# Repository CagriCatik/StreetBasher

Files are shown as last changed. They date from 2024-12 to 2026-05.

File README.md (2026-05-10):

<h1 align="center">StreetBasher: 3D-Printed RC Car Project</h1>

<p align="center">
  
  
</p>

**StreetBasher** is an open-source, 3D-printed RC car designed for enthusiasts who love customization, engineering, and high-speed fun. This project provides everything you need to **assemble, modify, and fine-tune your own RC car**, including **detailed assembly guides, 3D-printable parts, and tuning instructions**.

**Build it. Customize it. Race it!**

---

## **Project Highlights**
- **Fully 3D-Printed Design:** Print your own chassis, suspension, and other essential components.
- **Customizable:** Modify the design to fit your preferences, from gearing ratios to wheel types.
- **Electronics & Hardware Integration:** Supports standard RC electronics, motors, and batteries.
- **Step-by-Step Documentation:** Easy-to-follow instructions for assembly and tuning.

---

## **Project Structure**
```
StreetBasher/
│── .github/workflows/       # GitHub Actions for automation & deployment
│── instructions/            # Documentation & assembly guides
│   ├── docs/                # MkDocs-based documentation
│   ├── sldprts/             # SolidWorks design files
│   ├── stls/                # STL files for 3D printing
│   ├── mkdocs.yml           # Configuration for MkDocs documentation
│── original/                # Raw design files or legacy versions
│── .gitignore               # Ignored files
│── README.md                # Project overview (this file)
│── requirements.txt         # Dependencies for documentation setup
```

---

## **Getting Started**
### **1. Print the Parts**
Download the **STL files** from the `instructions/stls/` folder or from the official **Printables page**:  
**[StreetBasher on Printables](https://www.printables.com/model/700706-street-basher-3d-printed-rc-car-17)**

### **2. Gather the Components**
You will need the following:
- **3D-printed parts** (chassis, arms, suspension, etc.)
- **RC Electronics:** Brushless motor, ESC, receiver, and transmitter
- **Battery pack** (LiPo recommended)
- **Servo motor** for steering
- **Screws & Fasteners** (size details in the docs)

### **3. Assemble & Tune**
Follow the **step-by-step assembly guide** in `instructions/docs/` to build your RC car.  
Once built, fine-tune it using the tuning instructions for **better handling and speed**.

---

Complete guides, 3D model previews, and technical tutorials are available in the official documentation portal.

[**View Documentation Portal**](https://cagricatik.github.io/StreetBasher/)

---

## **Documentation Highlights**
- **Interaktive 3D Previews**: View every part directly in your browser.
- **Detailed BOM**: Full parts list with direct purchase links and cost analysis.
- **Assembly Guides**: Step-by-step instructions for a successful build.

---

## **Getting Started**
```sh
# Install dependencies
pip install -r requirements.txt

# Run MkDocs
mkdocs serve
```
Then open **http://127.0.0.1:8000** in your browser.

---

**Source:** [StreetBasher on Printables](https://www.printables.com/model/700706-street-basher-3d-printed-rc-car-17)

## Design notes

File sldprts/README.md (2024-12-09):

# SolidWorks Parts

---

## Chassis
| Part Name | Status | Material | Supports |
|---|---|---|---|
| Center_Front_bumper.sldprt | ✅ | Tough / Standard  | Yes |
| Front_body_brace_1.sldprt | ❌ | Tough / Standard  | No |
| Front_body_brace_2.sldprt | ❌ | Tough / Standard  | No |
| Front_body_brace_insert.sldprt| ❌ | Standard | No |
| Front_spliter.sldprt | ❌ | Tough / Flexible  | No |
| Rear_difuser_body.sldprt | ❌ | Standard | Yes |
| Rear_wing_brace_L.sldprt | ❌ | Tough / Standard  | No |
| Rear_wing_brace_R.sldprt | ❌ | Tough / Standard  | No |
| Center_body.sldprt | ❌ | Standard | Yes |
| Front_body.sldprt | ❌ | Standard | Yes |
| Front_brace.sldprt | ❌ | Standard | No |
| Rear_body.sldprt | ❌ | Standard | Yes |
| Rear_brace.sldprt | ❌ | Standard | No |

---

## Body Roll Cage

| Part Name | Status | Material | Supports |
|---|---|---|---|
| Back_Bottom_L.stl | ❌ | Tough / Flexible | Yes |
| Back_Bottom_R.stl | ❌ | Tough / Flexible | Yes |
| Back_Cage.stl | ❌ | Tough / Flexible | Yes |
| Back_Roof.stl | ❌ | Tough / Flexible | No |
| Back_Top_L.stl | ❌ | Tough / Flexible | No |
| Back_Top_R.stl | ❌ | Tough / Flexible | No |
| Front_bumper_bottom.stl | ❌ | Flexible | No |
| Front_bumper_holder_L.stl | ❌ | Flexible | No |
| Front_bumper_holder_R.stl | ❌ | Flexible | No |
| Front_bumper_L.stl | ❌ | Flexible | No |
| Front_bumper_R.stl | ❌ | Flexible | No |
| Front_bumper_top.stl | ❌ | Flexible | No |
| Hood_panel.stl | ❌ | Tough / Flexible | No |
| Mud_Guard.stl | ❌ | Tough / Flexible | Yes |
| Roof.stl | ❌ | Tough / Flexible | No |
| Roof_Panel.stl | ❌ | Tough / Flexible | No |
| Side_L.stl | ❌ | Tough / Flexible | Yes |
| Side_R.stl | ❌ | Tough / Flexible | Yes |

---
## Center Drive
---
## Electronics
---
## Differential
---
## Sway Bar
---
## Front Suspension
---
## Rear Suspension
---
## Steering
---
## Wing

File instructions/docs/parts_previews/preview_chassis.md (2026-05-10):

# Chassis 3D Previews

Explore all Chassis components in 3D. Drag to rotate, scroll to zoom.

---

## Front-Bumper Components

### Center Front Bumper

### Front Body Brace 1

### Front Body Brace 2

### Front Body Brace Insert

### Front Spliter

## Rear-Diffuser Components

### Rear Diffuser Body

### Rear Wing Brace L

### Rear Wing Brace R

## General Chassis Components

### Center Body

### Front Body

### Front Brace

### Rear Body

### Rear Brace

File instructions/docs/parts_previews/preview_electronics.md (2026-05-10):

# Electronics 3D Previews

Explore all Electronics components in 3D. Drag to rotate, scroll to zoom.

---

### Battery Tray L

### Battery Tray R

### Ele Box Body Esc

### Ele Box Body Wp8Bl150

### Ele Cover

### Fan Shroud

### On Off Switch Holder Wp8Bl150

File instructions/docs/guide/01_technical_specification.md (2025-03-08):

# **Technical Specification**

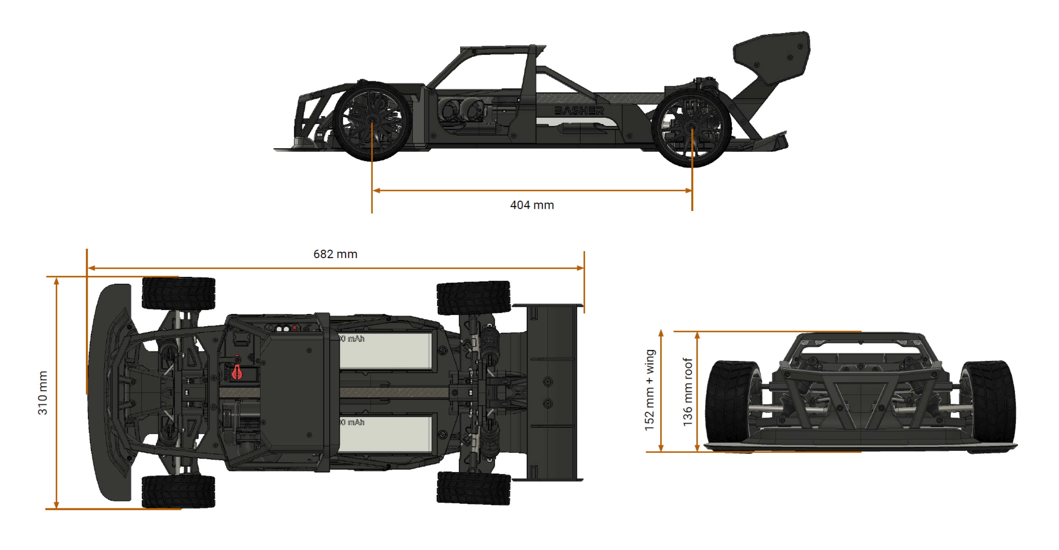
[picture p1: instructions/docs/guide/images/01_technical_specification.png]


## **1. General Information**
- **Model Name**: StreetBASHER  
- **Type**: High-performance RC Car Chassis (3D Printable)  
- **Application**: Hobbyist & Competitive RC Car Racing  
- **Scale**: Approx. 1:8  

## **2. Dimensions**
- **Overall Length**: 682 mm  
- **Wheelbase**: 404 mm  
- **Overall Width**: 310 mm  
- **Overall Height**:  
  - 136 mm (roof height)  
  - 152 mm (including rear wing)  

## **3. Chassis & Frame**
- **Material**:  
  - **Recommended Filaments**: PLA+ (for prototyping), PETG, ABS, or Nylon (for durability)  
  - **Reinforced Sections**: Carbon Fiber Nylon (for stress-prone areas)  
- **Construction**: Modular frame with a reinforced roll cage  
- **Mounting Points**: Designed for M3 & M4 bolts for securing electronic components  
- **Battery Tray Size**: Fits standard 2S-4S LiPo battery packs  
- **Cooling & Ventilation**: Open-frame design for airflow  

## **4. Suspension System**
- **Independent Suspension**: Double wishbone front & rear  
- **Shock Mounting**: Adjustable shock absorber mounting points  
- **Shock Absorbers**: 3D-printable dampers (supports oil-filled aluminum shocks for better performance)  

## **5. Drivetrain & Wheels**
- **Drive Type**: 4WD (Modular for RWD conversion)  
- **Differentials**: Space for customizable gear differentials  
- **Wheel Hub Mount**: 12 mm hex hubs (compatible with standard RC wheels)  
- **Tire Compatibility**: Off-road & on-road rubber tires (3D-printable wheels with TPU tires)  

## **6. Electronics & Powertrain**
- **Motor Mounting**: Supports 540/550 brushless or brushed motors  
- **ESC Mounting**: Space for 60A-120A ESC with ventilation slots  
- **Servo Mount**: Standard 25T servo horn compatibility  
- **Receiver & Electronics Bay**: Dedicated space for receiver & wiring management  
- **Battery Type**: LiPo 2S-4S compatible with secure mounting  

## **7. Aerodynamics & Body Design**
- **Front Splitter**: Designed for downforce and handling stability  
- **Rear Wing**: Adjustable wing for aerodynamic tuning  
- **Body Panels**: Modular, detachable panels for easy replacement  
- **3D Printability Considerations**:  
  - Split into sections for easy printing and assembly  
  - Support-free design where possible  
  - Optimized wall thickness for weight reduction  

## **8. Assembly & Hardware Requirements**
- **Fasteners**: M3 & M4 screws, lock nuts, washers  
- **Bearings**: 8x16x5 mm standard RC bearings  
- **Axles & Drive Shafts**: Compatible with 3D-printed or metal options  

## **9. Printing Guidelines**
- **Recommended Print Settings**:  
  - **Layer Height**: 0.2 mm for fine detail, 0.3 mm for strength  
  - **Infill**: 30%-50% (higher in stress areas)  
  - **Wall Thickness**: 2-3 mm for structural parts  
  - **Supports**: Minimal (optimized for overhangs and bridges)  
- **Material Notes**:  
  - PLA+ for prototyping  
  - PETG or ABS for functional parts  
  - TPU for flexible parts (bumpers, tires)  
  - Carbon Fiber Nylon for chassis reinforcement

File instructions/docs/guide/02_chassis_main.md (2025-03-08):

# Chassis Assembly 

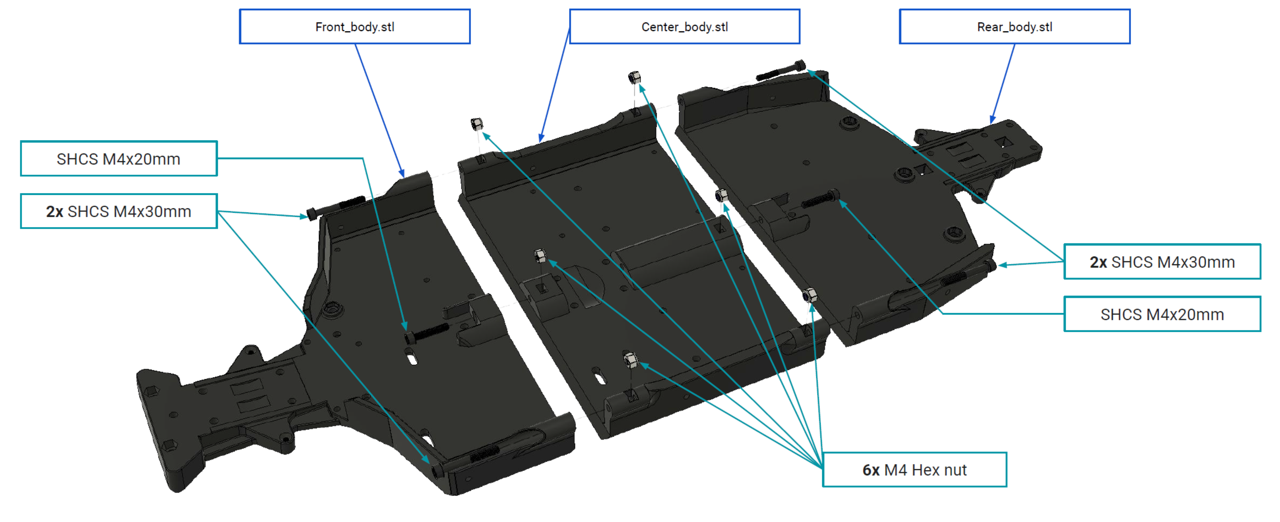
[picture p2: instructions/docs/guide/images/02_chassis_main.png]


## Chassis Components

The chassis is composed of three main parts:

- **Front_body.stl** - The front section of the chassis, which houses essential components such as the steering mechanism.
- **Center_body.stl** - The middle section of the chassis, which connects the front and rear sections and serves as the structural base for the electronic components.
- **Rear_body.stl** - The rear section of the chassis, which provides mounting points for the drivetrain and suspension components.

## Fasteners and Assembly Hardware
The assembly of the chassis requires the following fasteners:

- **SHCS (Socket Head Cap Screw) M4x20mm** - Used to join the front and center chassis sections.
- **2x SHCS M4x30mm** - Used to reinforce the connection between the front and center chassis.
- **2x SHCS M4x30mm** - Used to connect the center and rear chassis sections.
- **SHCS M4x20mm** - Additional reinforcement screw for securing the rear chassis.
- **6x M4 Hex Nuts** - Used to secure the M4 screws and prevent loosening during operation.

## Assembly Instructions

### Step 1: Preparing the Parts

1. Print the three chassis parts: **Front_body.stl, Center_body.stl, and Rear_body.stl** using a high-strength filament such as PETG or ABS for durability.
2. Ensure all printed parts are clean and free of excess filament or debris.

### Step 2: Connecting the Front and Center Sections

1. Align the **Front_body.stl** and **Center_body.stl** so that the mounting holes match.
2. Insert **SHCS M4x20mm** into the designated holes and loosely secure them.
3. Insert **2x SHCS M4x30mm** for added stability.
4. Attach **M4 Hex Nuts** to the screws and tighten them securely using an Allen key and a wrench.

### Step 3: Connecting the Center and Rear Sections

1. Align the **Center_body.stl** with **Rear_body.stl**, ensuring a proper fit.
2. Insert **2x SHCS M4x30mm** through the mounting holes.
3. Secure the screws using **M4 Hex Nuts** and tighten appropriately.
4. Insert the additional **SHCS M4x20mm** as a reinforcement screw and secure it with an **M4 Hex Nut**.

### Step 4: Final Tightening and Inspection

1. Verify all screws are tightened securely but not overtightened to avoid damaging the plastic.
2. Ensure that the chassis sections are properly aligned and free from gaps.
3. Check the structural integrity by applying light pressure to confirm a rigid connection.

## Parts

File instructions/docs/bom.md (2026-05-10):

# Bill of Materials

---

> [!NOTE]
> Looking for a price estimate? Check the detailed [Cost Analysis](cost_analysis.md) for a full breakdown of the build expenses.

## Drivetrain
| Part Name | Qty | Link  |
|---|-----|---|
| Front and rear Differential 43t + 10t pinion | 1x  | [link](https://s.click.aliexpress.com/e/_DezHD4Z) |
| Center differential 46t | 1x  | [link](https://s.click.aliexpress.com/e/_DBMWCD7) |
| CVD driveshaft Front | 2x  | [link](https://s.click.aliexpress.com/e/_DBLZZkv) |
| CVD driveshaft Back | 2x  | [link](https://s.click.aliexpress.com/e/_DCe5sf3) |
| Pinion gear 19T - 27T | 1x  | [link](https://s.click.aliexpress.com/e/_DE87qn7) |
| Drive shaft cup | 2x  | [link](https://s.click.aliexpress.com/e/_DnK3Nz7) |
| Driveshaft front to center (103.5mm) | 1x  | [link](https://s.click.aliexpress.com/e/_DmfG4It) |
| Driveshaft center to rear (170mm) | 1x  | [link](https://s.click.aliexpress.com/e/_DEjV5ez) |
| Wheel Hex | 4x  | [link](https://s.click.aliexpress.com/e/_DcxLlkt) |
| GRP 1:8 GT (S5 Medium) / Tyre 17mm Wheel Hex | 4x  | [link](https://s.click.aliexpress.com/e/_DkhpzbJ) |

---

## Electronics
| Part Name | Qty | Link  |
|---|-----|---|
| Servo + arm (DS3235 SSG-180) | 1x  | [link](https://s.click.aliexpress.com/e/_DDBty1r) |
| ESC 150A 6S / WP-8BL150 | 1x  | [link](https://s.click.aliexpress.com/e/_DdwzgTF) |
| Motor 4092 1420KV | 1x  | [link](https://s.click.aliexpress.com/e/_DEm0t2l) |
| Motor heatsink | 1x  | [link](https://s.click.aliexpress.com/e/_DCOEgbT) |
| 3s 5000mah (max dimensions 155x53mm) | 2x  | [link](https://chinahobbyline.com/products/cnhl-gplus-series-5000mah-11-1v-3s-70c-lipo-battery-with-xt90-plug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) |
| FlySky FS-GT5 +bs6 | 1x  | [link](https://s.click.aliexpress.com/e/_DkkQyyV) |

---

## Bearings
| Part Name | Qty | Link  |
|---|-----|---|
| 15x21x4mm (wheel inner) | 4x  | [link](https://s.click.aliexpress.com/e/_Dm0D3dj) |
| 8x16x5mm (wheel outer, diff) | 10x | |
| 5x11x4mm (diff pinion outer) | 2x  | |
| 8x19x6mm (diff pinion inner) | 2x  | |
| 6x10x3 (steering) | 4x  | |
| 3x6x2.5mm flange bearing (steering) | 4x  | [link](https://s.click.aliexpress.com/e/_DEKfLYD) |

---

## Screws
| Part Name | Qty  | Link  |
|---|---|---|
| M3 hex nut (self-locking) | 47x  | [link](https://s.click.aliexpress.com/e/_Dl5C057) |
| M4 hex nut (self-locking) | 50x  | |
| M3x7mm washer | 8x | [link](https://s.click.aliexpress.com/e/_Dl5C057) |
| M6x10mm Grub Screw | 4x | [link](https://s.click.aliexpress.com/e/_DdRgkKV) |
| M3x5mm Grub Screw | 8x | |
| SHCS M3x8mm | 5x | [link](https://s.click.aliexpress.com/e/_DkRgcZT) |
| SHCS M3x10mm | 13x  | |
| SHCS M3x14mm | 28x  | |
| SHCS M3x16mm | 7x | |
| SHCS M3x18mm | 10x  | |
| SHCS M3x20mm | 20x  | |
| SHCS M3x25mm | 17x  | |
| SHCS M3x30mm | 16x  | |
| FHCS M3x6mm | 4x | [link](https://s.click.aliexpress.com/e/_Dd5kyh3) |
| FHCS M3x10mm | 4x | |
| FHCS M3x12mm | 6x | |
| FHCS M3x14mm | 12x  | |
| FHCS M3x16mm | 8x | |
| SHCS M4x12mm | 13x  | [link](https://s.click.aliexpress.com/e/_DkRgcZT) |
| SHSC M4x16mm | 8x | |
| SHCS M4x20mm | 10x  | |
| SHCS M4x30mm | 8x | |
| SHCS M4x40mm | 2x | |
| SHCS M4x45mm | 4x | |
| SHCS M4x55mm | 2x | |
| SHCS M4x60mm | 4x | |
| SHCS M4x70mm | 4x | |
| FHCS M4x16mm | 11x  | [link](https://s.click.aliexpress.com/e/_Dd5kyh3) |
| FHCS M4x20mm | 4x | |

---

## Other
| Part Name | Qty | Link  |
|---|-----|---|
| Carbon center brace 15x15x13 (365mm) | 1x  | [link](https://s.click.aliexpress.com/e/_DdjCkoN) |
| Front arms pivot ball | 4x  | [link](https://s.click.aliexpress.com/e/_DB9CWiD) |
| Ball head 6.8x8.2x3 | 8x  | [link](https://s.click.aliexpress.com/e/_DCgGGoN) |
| Ball head 5.8x6x3 | 6x  | [link](https://s.click.aliexpress.com/e/_DCRDovT) |
| Front hub nut | 4x  | [link](https://s.click.aliexpress.com/e/_DmmpUX3) |
| Front and Rear Shocks | 1x  | [link](https://s.click.aliexpress.com/e/_DkQfMkZ) |
| Servo saver spring - 20mm length / 2mm wire / 16mm outer | 1x  | [link](https://s.click.aliexpress.com/e/_DFZ1YtB) |
| Arm link rear M5x50mm | 2x  | [link](https://s.click.aliexpress.com/e/_DBpFie1) |
| Arm link front M4x40mm | 2x  | [link](https://s.click.aliexpress.com/e/_DBpFie1) |
| Swaybar front | 1x  | ARA330257 |
| Swaybar rear | 1x  | ARAC9080 |
| Wheel shims M8x10x0.1 | 4-8x| [link](https://s.click.aliexpress.com/e/_DnN8B3B) |

---

## Accessories
| Part Name | Qty | Link  |
|---|-----|---|
| White lithium grease (external diff) | | |
| Oil 2000cSt (shocks) | | [link](https://s.click.aliexpress.com/e/_Dm6LZ6t) |
| Oil 100k cSt (center diff) | | |
| Oil 30k cSt (front/rear diff) | | |
| Loctite 243 | | |
| Battery strap 15-20mm x 240-280mm | 4x  | [link](https://s.click.aliexpress.com/e/_DEA4Nfr) |
| Foam padding 20mm 5mm thick | 1m  | [link](https://s.click.aliexpress.com/e/_DDHuyXL) |
| **Optional** Lipo Battery Voltage Tester | 1x  | [link](https://s.click.aliexpress.com/e/_DCnddTr) |

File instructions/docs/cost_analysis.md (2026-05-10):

# Project Cost Analysis

Estimated total cost for building the StreetBasher RC car based on current market prices (AliExpress, CNHL, etc.).

---

## Component Cost Breakdown

| Category | Item | Individual Price | Quantity | Subtotal |
| :--- | :--- | :--- | :--- | :--- |
| **Drivetrain** | Differential Set (Front/Rear) | 75.39 € | 1 Set | 75.39 € |
| | Center Differential | 56.84 € | 1 | 56.84 € |
| | Tires (GRP 1:8 GT Set) | 84.34 € | 1 Set | 84.34 € |
| **Electronics** | Servo (9imod 35kg High Torque) | 22.19 € | 1 | 22.19 € |
| | ESC 150A (Waterproof) | 143.98 € | 1 | 143.98 € |
| | Motor 4092 (Brushless) | 76.39 € | 1 | 76.39 € |
| | Battery 3S 5000mAh (CNHL) | 33.53 € | 2 | 67.06 € |
| | Transmitter (Flysky FS-GT5) | 72.53 € | 1 | 72.53 € |
| **Suspension** | Big Bore Shock Set | 45.78 € | 1 Set | 45.78 € |
| **Total Build Cost** | | | | **~644.50 €** |

---

## Savings & Optimization

> [!TIP]
> **Potential Savings: ~200 €+**
> 
> By utilizing "New User" discounts on AliExpress, current "Choice" deals, and combining shipping, the total cost can be reduced to approximately **439.22 €**.

### Tips for Procurement
*   **AliExpress Coins**: Use the mobile app to collect coins for additional 2-5% off.
*   **Choice Shipping**: Look for items marked as "Choice" for free 10-day shipping and combined delivery.
*   **Battery Safety**: Always order batteries from local warehouses (EU/US) to avoid long shipping times and customs issues.

---

*Note: Prices are subject to change and may vary based on region and shipping costs.*

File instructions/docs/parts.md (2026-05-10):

# Printed Part Lists

**Materials Key**

- **Tough**: PC-Max / PC-CF
- **Flexible**: TPU 98A
- **Standard**: [PLA Metall](https://eu.store.bambulab.com/de/products/pla-metall?variant=46797850902876)

---

## Chassis

### Front Parts

| Part Name | Status | Material | Supports | Link |
|---|---|---|---|---|
| Center_Front_bumper.stl | ✅ | Standard | Yes | [🔗](https://github.com/CagriCatik/StreetBasher/blob/main/stls/Chassis/Front-Bumper/Center_Front_bumper.stl) |
| Front_body_brace_1.stl | ✅ | Standard | No | [🔗](https://github.com/CagriCatik/StreetBasher/blob/main/stls/Chassis/Front-Bumper/Front_body_brace_1.stl) |
| Front_body_brace_2.stl | ✅ | Standard | No | [🔗](https://github.com/CagriCatik/StreetBasher/blob/main/stls/Chassis/Front-Bumper/Front_body_brace_2.stl) |
| Front_body_brace_insert.stl  | ✅ | Standard | No | [🔗](https://github.com/CagriCatik/StreetBasher/blob/main/stls/Chassis/Front-Bumper/Front_body_brace_insert.stl) |
| Front_spliter.stl | ✅ | Tough / Flexible | No | [🔗](https://github.com/CagriCatik/StreetBasher/blob/main/stls/Chassis/Front-Bumper/Front_spliter.stl) |
| Front_body.stl | ✅ | Standard | Yes | [🔗](https://github.com/CagriCatik/StreetBasher/blob/main/stls/Chassis/Front_body.stl) |
| Front_brace.stl | ❌ | Standard | No | [🔗](https://github.com/CagriCatik/StreetBasher/blob/main/stls/Chassis/Front_brace.stl) |

### Rear Parts

| Part Name | Status | Material | Supports | Link |
|---|---|---|---|---|
| Rear_difuser_body.stl  | ✅ | Standard | Yes | [🔗](https://github.com/CagriCatik/StreetBasher/blob/main/stls/Chassis/Rear-Diffuser/Rear_Diffuser_Body.stl) |
| Rear_wing_brace_L.stl  | ❌ | Tough / Standard  | No | [🔗](https://github.com/CagriCatik/StreetBasher/blob/main/stls/Chassis/Rear-Diffuser/Rear_wing_brace_L.stl) |
| Rear_wing_brace_R.stl  | ❌ | Tough / Standard  | No | [🔗](https://github.com/CagriCatik/StreetBasher/blob/main/stls/Chassis/Rear-Diffuser/Rear_wing_brace_R.stl) |
| Rear_body.stl | ✅ | Standard | Yes | [🔗](https://github.com/CagriCatik/StreetBasher/blob/main/stls/Chassis/Rear_body.stl) |
| Rear_brace.stl | ✅ | Standard | No | [🔗](https://github.com/CagriCatik/StreetBasher/blob/main/stls/Chassis/Rear_brace.stl) |

### Center Part

| Part Name | Status | Material  | Supports | Link |
|---|---|---|---|---|
| Center_body.stl | ✅ | Standard  | Yes | [🔗](https://github.com/CagriCatik/StreetBasher/blob/main/stls/Chassis/Center_body.stl) |

---

## Body Roll Cage

| Part Name | Status | Material | Supports | Link |
|---|---|---|---|---|
| Back_Bottom_L.stl | ✅ | Tough / Flexible | Yes | [🔗](https://github.com/CagriCatik/StreetBasher/blob/main/stls/Body-Roll-Cage/Back_Bottom_L.stl) |
| Back_Bottom_R.stl | ✅ | Tough / Flexible | Yes | [🔗](https://github.com/CagriCatik/StreetBasher/blob/main/stls/Body-Roll-Cage/Back_Bottom_R.stl) |
| Back_Cage.stl | ✅ | Tough / Flexible | Yes | [🔗](https://github.com/CagriCatik/StreetBasher/blob/main/stls/Body-Roll-Cage/Back_Cage.stl) |
| Back_Roof.stl | ✅ | Tough / Flexible | No | [🔗](https://github.com/CagriCatik/StreetBasher/blob/main/stls/Body-Roll-Cage/Back_Roof.stl) |
| Back_Top_L.stl | ✅ | Tough / Flexible | No | [🔗](https://github.com/CagriCatik/StreetBasher/blob/main/stls/Body-Roll-Cage/Back_Top_L.stl) |
| Back_Top_R.stl | ✅ | Tough / Flexible | No | [🔗](https://github.com/CagriCatik/StreetBasher/blob/main/stls/Body-Roll-Cage/Back_Top_R.stl) |
| Front_bumper_bottom.stl | ✅ | Flexible | No | [🔗](https://github.com/CagriCatik/StreetBasher/blob/main/stls/Body-Roll-Cage/Front_bumper_bottom.stl) |
| Front_bumper_holder_L.stl | ✅ | Flexible | No | [🔗](https://github.com/CagriCatik/StreetBasher/blob/main/stls/Body-Roll-Cage/Front_bumper_holder_L.stl) |
| Front_bumper_holder_R.stl | ✅ | Flexible | No | [🔗](https://github.com/CagriCatik/StreetBasher/blob/main/stls/Body-Roll-Cage/Front_bumper_holder_R.stl) |
| Front_bumper_L.stl | ❌ | Flexible | No | [🔗](https://github.com/CagriCatik/StreetBasher/blob/main/stls/Body-Roll-Cage/Front_bumper_L.stl) |
| Front_bumper_R.stl | ❌ | Flexible | No | [🔗](https://github.com/CagriCatik/StreetBasher/blob/main/stls/Body-Roll-Cage/Front_bumper_R.stl) |
| Front_bumper_top.stl | ❌ | Flexible | No | [🔗](https://github.com/CagriCatik/StreetBasher/blob/main/stls/Body-Roll-Cage/Front_bumper_top.stl) |
| Hood_panel.stl | ✅ | Tough / Flexible | No | [🔗](https://github.com/CagriCatik/StreetBasher/blob/main/stls/Body-Roll-Cage/Hood_panel.stl) |
| Mud_Guard.stl | ✅ | Tough / Flexible | Yes | [🔗](https://github.com/CagriCatik/StreetBasher/blob/main/stls/Body-Roll-Cage/Mud_Guard.stl) |
| Roof.stl | ✅ | Tough / Flexible | No | [🔗](https://github.com/CagriCatik/StreetBasher/blob/main/stls/Body-Roll-Cage/Roof.stl) |
| Roof_Panel.stl | ✅ | Tough / Flexible | No | [🔗](https://github.com/CagriCatik/StreetBasher/blob/main/stls/Body-Roll-Cage/Roof_Panel.stl) |
| Side_L.stl | ✅ | Tough / Flexible | Yes | [🔗](https://github.com/CagriCatik/StreetBasher/blob/main/stls/Body-Roll-Cage/Side_L.stl) |
| Side_R.stl | ✅ | Tough / Flexible | Yes | [🔗](https://github.com/CagriCatik/StreetBasher/blob/main/stls/Body-Roll-Cage/Side_R.stl) |

---

## Center Drive

| Part Name | Status | Material | Supports | Link |
|---|---|---|---|---|
| Motor_support_mount_1.stl | ✅ | Standard | No | [🔗](https://github.com/CagriCatik/StreetBasher/blob/main/stls/Center-Drive/Motor-Mount/Motor_support_mount_1.stl) |
| Motor_support_mount_2.stl | ✅ | Standard | No | [🔗](https://github.com/CagriCatik/StreetBasher/blob/main/stls/Center-Drive/Motor-Mount/Motor_support_mount_2.stl) |
| Motor_support_mount_3.stl | ✅ | Standard | No | [🔗](https://github.com/CagriCatik/StreetBasher/blob/main/stls/Center-Drive/Motor-Mount/Motor_support_mount_3.stl) |
| Center_brace_holder.stl | ✅ | Tough | No | [🔗](https://github.com/CagriCatik/StreetBasher/blob/main/stls/Center-Drive/Center_brace_holder.stl) |
| Center_diff_bottom.stl | ✅ | Standard | Yes | [🔗](https://github.com/CagriCatik/StreetBasher/blob/main/stls/Center-Drive/Center_diff_bottom.stl) |
| Center_diff_top.stl | ✅ | Standard | No | [🔗](https://github.com/CagriCatik/StreetBasher/blob/main/stls/Center-Drive/Center_diff_top.stl) |
| Center_diff_top_cover.stl | ✅ | Standard | Yes | [🔗](https://github.com/CagriCatik/StreetBasher/blob/main/stls/Center-Drive/Center_diff_top_cover.stl) |

---

## Electronics

| Part Name | Status | Material | Supports | Link |
|---|---|---|---|---|
| Battery_tray_L.stl | ✅ | Standard | Yes | [🔗](https://github.com/CagriCatik/StreetBasher/blob/main/stls/Electronics/Battery_tray_L.stl) |
| Battery_tray_R.stl | ✅ | Standard | Yes | [🔗](https://github.com/CagriCatik/StreetBasher/blob/main/stls/Electronics/Battery_tray_R.stl) |
| Ele_box_body_WP8BL150.stl | ❌ | Standard | Yes | [🔗](https://github.com/CagriCatik/StreetBasher/blob/main/stls/Electronics/Ele_box_body_WP8BL150.stl) |
| Ele_box_body_ESC.stl | ❌ | Standard | Yes | [🔗](https://github.com/CagriCatik/StreetBasher/blob/main/stls/Electronics/Ele_box_body_ESC.stl) |
| Ele_cover.stl | ✅ | Standard | Yes | [🔗](https://github.com/CagriCatik/StreetBasher/blob/main/stls/Electronics/Ele_cover.stl) |
| Fan_shroud.stl | ✅ | Standard | No | [🔗](https://github.com/CagriCatik/StreetBasher/blob/main/stls/Electronics/Fan_shroud.stl) |
| On_Off_switch_holder_WP8BL150.stl | ❌ | Standard | Yes | [🔗](https://github.com/CagriCatik/StreetBasher/blob/main/stls/Electronics/On_Off_switch_holder_WP8BL150.stl) |

---

## Differential

### Front

| Part Name | Status | Material | Supports | Link |
|---|---|---|---|---|
| Diff_body.stl | ✅ | Tough | Yes | [🔗](https://github.com/CagriCatik/StreetBasher/blob/main/stls/Differential/Front/Diff_body.stl) |
| Diff_cover.stl | ✅ | Tough / Standard | Yes | [🔗](https://github.com/CagriCatik/StreetBasher/blob/main/stls/Differential/Front/Diff_cover.stl) |
| Diff_sway_bar_cover.stl | ✅ | Standard | Yes | [🔗](https://github.com/CagriCatik/StreetBasher/blob/main/stls/Differential/Front/Diff_sway_bar_cover.stl) |

### Rear

| Part Name | Status | Material | Supports | Link |
|---|---|---|---|---|
| Diff_body.stl | ✅ | Tough | Yes | [🔗](https://github.com/CagriCatik/StreetBasher/blob/main/stls/Differential/Rear/Diff_body.stl) |
| Diff_cover.stl | ✅ | Tough / Standard | Yes | [🔗](https://github.com/CagriCatik/StreetBasher/blob/main/stls/Differential/Rear/Diff_cover.stl) |
| Diff_sway_bar_cover.stl | ❌ | Standard | Yes | [🔗](https://github.com/CagriCatik/StreetBasher/blob/main/stls/Differential/Rear/Diff_sway_bar_cover.stl) |

---

## Sway Bar

### Front

| Part Name | Status | Material  | Supports | Link |
|---|---|---|---|---|
| Sway_bar_joint_x2.stl | ❌ | Tough | No | [🔗](https://github.com/CagriCatik/StreetBasher/blob/main/stls/Sway-Bar/Front/Sway_bar_joint_x2.stl) |
| Sway_bar_link_x2.stl  | ❌ | Tough | No | [🔗](https://github.com/CagriCatik/StreetBasher/blob/main/stls/Sway-Bar/Front/Sway_bar_link_x2.stl) |

### Rear

| Part Name | Status | Material  | Supports | Link |
|---|---|---|---|---|
| Sway_bar_joint_x2.stl | ❌ | Tough | No | [🔗](https://github.com/CagriCatik/StreetBasher/blob/main/stls/Sway-Bar/Rear/Sway_bar_joint_x2.stl) |
| Sway_bar_link_x2.stl  | ❌ | Tough | No | [🔗](https://github.com/CagriCatik/StreetBasher/blob/main/stls/Sway-Bar/Rear/Sway_bar_link_x2.stl) |

---

## Front Suspension

| Part Name | Status | Material  | Supports | Link |
|---|---|---|---|---|
| Ball_Lock_x2.stl | ❌ | Standard  | Yes | [🔗](https://github.com/CagriCatik/StreetBasher/blob/main/stls/Front-Suspension/Ball_Lock_x2.stl) |
| Front_arm_bottom_L.stl | ✅ | Tough | No | [🔗](https://github.com/CagriCatik/StreetBasher/blob/main/stls/Front-Suspension/Front-Left-Arm/Front_arm_bottom_L.stl) |
| Front_arm_Top_L.stl | ✅ | Tough | No | [🔗](https://github.com/CagriCatik/StreetBasher/blob/main/stls/Front-Suspension/Front-Left-Arm/Front_arm_Top_L.stl) |
| Front_hub_L.stl | ✅ | Tough | Yes | [🔗](https://github.com/CagriCatik/StreetBasher/blob/main/stls/Front-Suspension/Front-Left-Arm/Front_hub_L.stl) |
| Front_arm_bottom_R.stl | ✅ | Tough | No | [🔗](https://github.com/CagriCatik/StreetBasher/blob/main/stls/Front-Suspension/Front-Right-Arm/Front_arm_bottom_R.stl) |
| Front_arm_Top_R.stl | ✅ | Tough | No | [🔗](https://github.com/CagriCatik/StreetBasher/blob/main/stls/Front-Suspension/Front-Right-Arm/Front_arm_Top_R.stl) |
| Front_hub_R.stl | ✅ | Tough | Yes | [🔗](https://github.com/CagriCatik/StreetBasher/blob/main/stls/Front-Suspension/Front-Right-Arm/Front_hub_R.stl) |
| Tie_rod_M4_1.stl | ✅ | Tough | Yes | [🔗](https://github.com/CagriCatik/StreetBasher/blob/main/stls/Front-Suspension/Tie_rod_M4_1.stl) |
| Tie_rod_M4_2.stl | ✅ | Tough | Yes | [🔗](https://github.com/CagriCatik/StreetBasher/blob/main/stls/Front-Suspension/Tie_rod_M4_2.stl) |
| Front_arm_holder_front.stl | ✅ | Tough | No | [🔗](https://github.com/CagriCatik/StreetBasher/blob/main/stls/Front-Suspension/Front_arm_holder_front.stl) |
| Front_arm_holder_rear.stl | ✅ | Tough | No | [🔗](https://github.com/CagriCatik/StreetBasher/blob/main/stls/Front-Suspension/Front_arm_holder_rear.stl) |
| Front_center_brace_holder.stl| ✅ | Standard  | Yes | [🔗](https://github.com/CagriCatik/StreetBasher/blob/main/stls/Front-Suspension/Front_center_brace_holder.stl) |
| Front_tower.stl | ✅ | Tough | No | [🔗](https://github.com/CagriCatik/StreetBasher/blob/main/stls/Front-Suspension/Front_tower.stl) |
| Shock_adapter_1_2x.stl | ❌ | Standard  | No | [🔗](https://github.com/CagriCatik/StreetBasher/blob/main/stls/Front-Suspension/Shock_adapter_1_2x.stl) |
| Shock_adapter_2_2x.stl | ❌ | Standard  | No | [🔗](https://github.com/CagriCatik/StreetBasher/blob/main/stls/Front-Suspension/Shock_adapter_2_2x.stl) |
| Top_arm_holder.stl | ❌ | Tough | No | [🔗](https://github.com/CagriCatik/StreetBasher/blob/main/stls/Front-Suspension/Top_arm_holder.stl) |
| Top_plate.stl | ❌ | Standard  | No | [🔗](https://github.com/CagriCatik/StreetBasher/blob/main/stls/Front-Suspension/Top_plate.stl) |

---

## Rear Suspension

| Part Name | Status | Material  | Supports | Link |
|---|---|---|---|---|
| Rear_arm_L.stl | ✅ | Tough | No | [🔗](https://github.com/CagriCatik/StreetBasher/blob/main/stls/Rear-Suspension/Rear-Left-Arm/Rear_arm_L.stl) |
| Rear_hub_L.stl | ✅ | Tough | Yes | [🔗](https://github.com/CagriCatik/StreetBasher/blob/main/stls/Rear-Suspension/Rear-Left-Arm/Rear_hub_L.stl) |
| Rear_arm_R.stl | ✅ | Tough | No | [🔗](https://github.com/CagriCatik/StreetBasher/blob/main/stls/Rear-Suspension/Rear-Right-Arm/Rear_arm_R.stl) |
| Rear_hub_R.stl | ✅ | Tough | Yes | [🔗](https://github.com/CagriCatik/StreetBasher/blob/main/stls/Rear-Suspension/Rear-Right-Arm/Rear_hub_R.stl) |
| Tie_rod_M5_1.stl | ✅ | Tough | Yes | [🔗](https://github.com/CagriCatik/StreetBasher/blob/main/stls/Rear-Suspension/Tie_rod_M5_1.stl) |
| Tie_rod_M5_2.stl | ✅ | Tough | Yes | [🔗](https://github.com/CagriCatik/StreetBasher/blob/main/stls/Rear-Suspension/Tie_rod_M5_2.stl) |
| Rear_arm_holder_front.stl  | ✅ | Tough | Yes | [🔗](https://github.com/CagriCatik/StreetBasher/blob/main/stls/Rear-Suspension/Rear_arm_holder_front.stl) |
| Rear_arm_holder_rear.stl | ✅ | Tough | Yes | [🔗](https://github.com/CagriCatik/StreetBasher/blob/main/stls/Rear-Suspension/Rear_arm_holder_rear.stl) |
| Rear_brace_holder.stl | ✅ | Standard  | Yes | [🔗](https://github.com/CagriCatik/StreetBasher/blob/main/stls/Rear-Suspension/Rear_brace_holder.stl) |
| Rear_tower.stl | ✅ | Tough | No | [🔗](https://github.com/CagriCatik/StreetBasher/blob/main/stls/Rear-Suspension/Rear_tower.stl) |
| Shock_adapter_1_2x.stl | ❌ | Standard  | No | [🔗](https://github.com/CagriCatik/StreetBasher/blob/main/stls/Rear-Suspension/Shock_adapter_1_2x.stl) |
| Shock_adapter_2_2x.stl | ❌ | Standard  | No | [🔗](https://github.com/CagriCatik/StreetBasher/blob/main/stls/Rear-Suspension/Shock_adapter_2_2x.stl) |

---

## Steering

| Part Name | Status | Material  | Supports | Link |
|---|---|---|---|---|
| Left_shaft_arm.stl | ✅ | Tough | Yes | [🔗](https://github.com/CagriCatik/StreetBasher/blob/main/stls/Steering/Left_shaft_arm.stl) |
| Right_tower_lower.stl | ✅ | Tough | Yes | [🔗](https://github.com/CagriCatik/StreetBasher/blob/main/stls/Steering/Right_tower_lower.stl) |
| Right_tower_upper.stl | ✅ | Tough | Yes | [🔗](https://github.com/CagriCatik/StreetBasher/blob/main/stls/Steering/Right_tower_upper.stl) |
| Servo_joint.stl | ✅ | Tough | No | [🔗](https://github.com/CagriCatik/StreetBasher/blob/main/stls/Steering/Servo_joint.stl) |
| Servo_saver_to_link.stl | ✅ | Tough | Yes | [🔗](https://github.com/CagriCatik/StreetBasher/blob/main/stls/Steering/Servo_saver_to_link.stl) |
| Servo_saver_top.stl | ✅ | Tough | Yes | [🔗](https://github.com/CagriCatik/StreetBasher/blob/main/stls/Steering/Servo_saver_top.stl) |
| Steering_center.stl | ✅ | Tough | Yes | [🔗](https://github.com/CagriCatik/StreetBasher/blob/main/stls/Steering/Steering_center.stl) |
| Steering_shaft_x4.stl | ❌ | Tough | No | [🔗](https://github.com/CagriCatik/StreetBasher/blob/main/stls/Steering/Steering_shaft_x4.stl) |

---

## Wing

| Part Name | Status | Material | Supports | Link |
|---|---|---|---|---|
| Side_wing_L.stl | ✅ | Tough / Flexible | No | [🔗](https://github.com/CagriCatik/StreetBasher/blob/main/stls/Wing/Side_wing_L.stl) |
| Side_wing_R.stl | ✅ | Tough / Flexible | No | [🔗](https://github.com/CagriCatik/StreetBasher/blob/main/stls/Wing/Side_wing_R.stl) |
| Wing_body.stl | ✅ | Tough / Flexible | No | [🔗](https://github.com/CagriCatik/StreetBasher/blob/main/stls/Wing/Wing_body.stl) |
---

## Test and Help

Essential tools and testing components to ensure proper fitment and assembly.

| Part Name | Status | Material  | Supports | Link |
|---|---|---|---|---|
| Fit_test.stl | ✅ | Standard  | No | [🔗](https://github.com/CagriCatik/StreetBasher/blob/main/stls/Test-and-Help/Fit_test.stl) |
| Front_ball_insert_helper.stl | ✅ | Standard  | No | [🔗](https://github.com/CagriCatik/StreetBasher/blob/main/stls/Test-and-Help/Front_ball_insert_helper.stl) |
| Rear_ball_inser_helper.stl | ✅ | Standard  | No | [🔗](https://github.com/CagriCatik/StreetBasher/blob/main/stls/Test-and-Help/Rear_ball_inser_helper.stl) |
| Wrench.stl | ✅ | Tough | No | [🔗](https://github.com/CagriCatik/StreetBasher/blob/main/stls/Test-and-Help/Wrench.stl) |

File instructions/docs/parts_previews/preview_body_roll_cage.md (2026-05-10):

# Body Roll Cage 3D Previews

Explore all Body Roll Cage components in 3D. Drag to rotate, scroll to zoom.

---

### Back Bottom L

### Back Bottom R

### Back Cage

### Back Roof

### Back Top L

### Back Top R

### Front Bumper L

### Front Bumper R

### Front Bumper Bottom

### Front Bumper Holder L

### Front Bumper Holder R

### Front Bumper Top

### Hood Panel

### Mud Guard

### Roof

### Roof Panel

### Side L

### Side R

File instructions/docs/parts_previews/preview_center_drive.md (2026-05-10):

# Center Drive 3D Previews

Explore all Center Drive components in 3D. Drag to rotate, scroll to zoom.

---

## Motor-Mount Components

### Motor Support Mount 1

### Motor Support Mount 2

### Motor Support Mount 3

## General Center Drive Components

### Center Brace Holder

### Center Diff Bottom

### Center Diff Top

### Center Diff Top Cover

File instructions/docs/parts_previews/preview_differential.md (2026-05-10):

# Differential 3D Previews

Explore all Differential components in 3D. Drag to rotate, scroll to zoom.

---

## Front Components

### Diff Body

### Diff Cover

### Diff Sway Bar Cover

## Rear Components

### Diff Body

### Diff Cover

### Diff Sway Bar Cover

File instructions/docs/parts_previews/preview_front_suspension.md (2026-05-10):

# Front Suspension 3D Previews

Explore all Front Suspension components in 3D. Drag to rotate, scroll to zoom.

---

## Front Right Arm Components

### Ball Lock X2

### Front Arm Top R

### Front Arm Bottom R

### Front Hub R

### Tie Rod M4 1

### Tie Rod M4 2

## Front-Left-Arm Components

### Ball Lock X2

### Front Arm Top L

### Front Arm Bottom L

### Front Hub L

### Tie Rod M4 1

### Tie Rod M4 2

## General Front Suspension Components

### Front Arm Holder Front

### Front Arm Holder Rear

### Front Center Brace Holder

### Front Tower

### Shock Adapter 1 2X

### Shock Adapter 2 2X

### Top Arm Holder

### Top Plate

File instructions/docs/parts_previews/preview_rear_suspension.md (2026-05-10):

# Rear Suspension 3D Previews

Explore all Rear Suspension components in 3D. Drag to rotate, scroll to zoom.

---

## Rear-Left-Arm Components

### Rear Arm L

### Rear Hub L

### Tie Rod M5 1

### Tie Rod M5 2

## Rear-Right-Arm Components

### Rear Arm R

### Rear Hub R

### Tie Rod M5 1

### Tie Rod M5 2

## General Rear Suspension Components

### Rear Arm Holder Front

### Rear Arm Holder Rear

### Rear Brace Holder

### Rear Tower

### Shock Adapter 1 2X

### Shock Adapter 2 2X

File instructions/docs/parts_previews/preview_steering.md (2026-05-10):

# Steering 3D Previews

Explore all Steering components in 3D. Drag to rotate, scroll to zoom.

---

### Left Shaft Arm

### Right Tower Lower

### Right Tower Upper

### Servo Joint

### Servo Saver To Link

### Servo Saver Top

### Steering Center

### Steering Shaft X4

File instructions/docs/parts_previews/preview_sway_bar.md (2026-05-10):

# Sway Bar 3D Previews

Explore all Sway Bar components in 3D. Drag to rotate, scroll to zoom.

---

## Front Components

### Sway Bar Joint X2

### Sway Bar Link X2

## Rear Components

### Sway Bar Joint X2

### Sway Bar Link X2

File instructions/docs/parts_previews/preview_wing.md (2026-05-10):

# Wing 3D Previews

Explore all Wing components in 3D. Drag to rotate, scroll to zoom.

---

### Side Wing L

### Side Wing R

### Wing Body

### Wing Mount

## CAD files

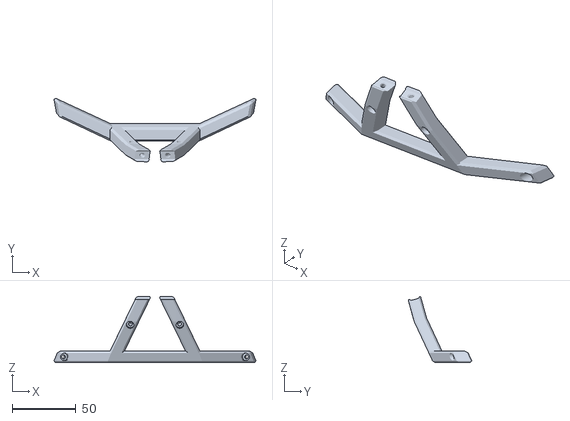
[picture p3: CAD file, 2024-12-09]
instructions/docs/assets/stls/Body-Roll-Cage/Front_bumper_top.stl
158.3 x 49.8 x 51.9

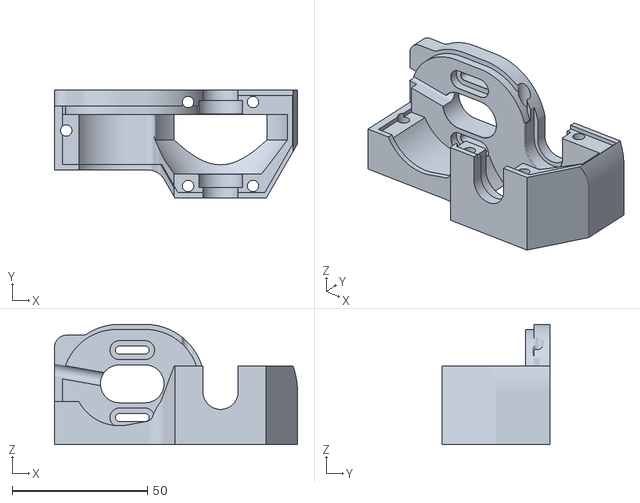
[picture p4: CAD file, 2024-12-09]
instructions/docs/assets/stls/Center-Drive/Center_diff_bottom.stl
89.8 x 40.0 x 44.5

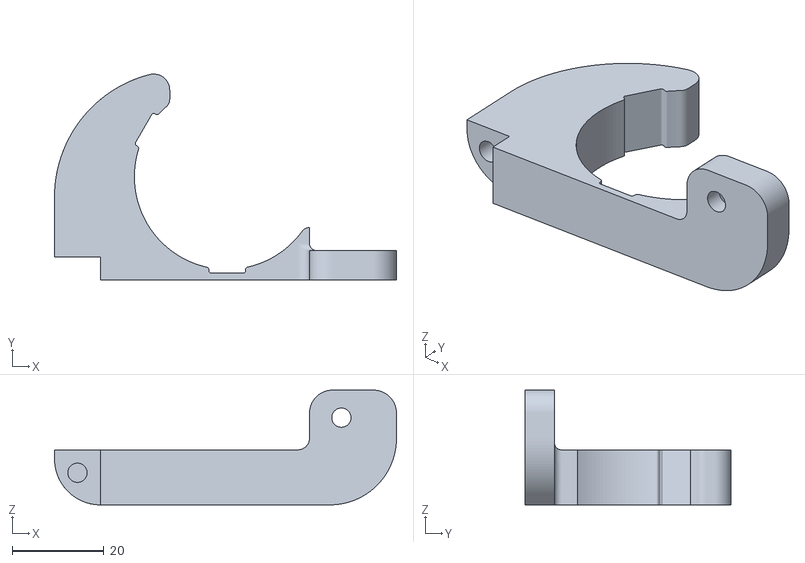
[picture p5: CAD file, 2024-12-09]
instructions/docs/assets/stls/Center-Drive/Motor-Mount/Motor_support_mount_1.stl
74.5 x 44.8 x 25.0

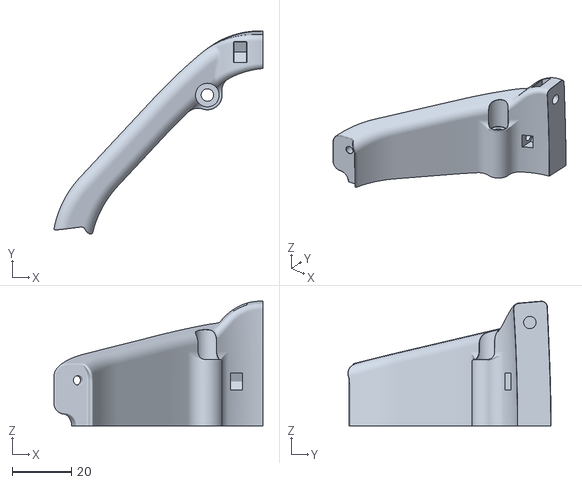
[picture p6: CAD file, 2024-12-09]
instructions/docs/assets/stls/Chassis/Front-Bumper/Front_body_brace_1.stl
70.6 x 68.7 x 42.2

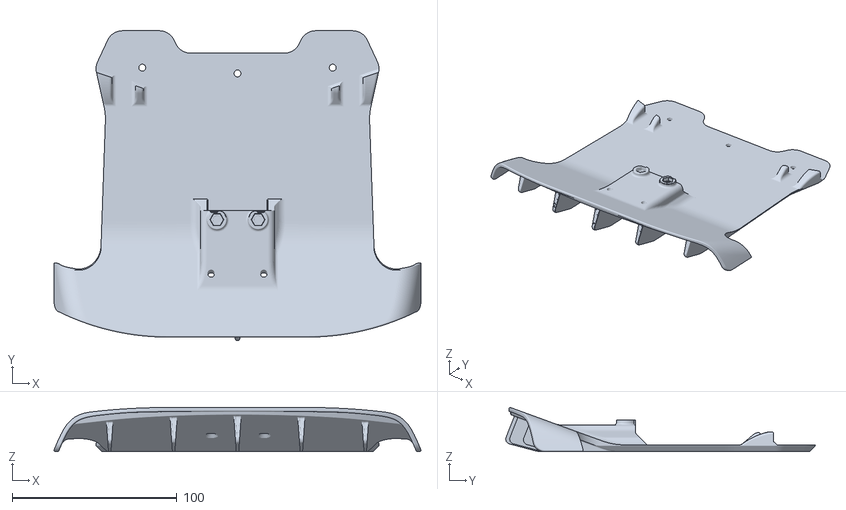
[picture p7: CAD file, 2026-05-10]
instructions/docs/assets/stls/Chassis/Rear-Diffuser/Rear_Diffuser_Body.stl
222.8 x 188.0 x 26.7

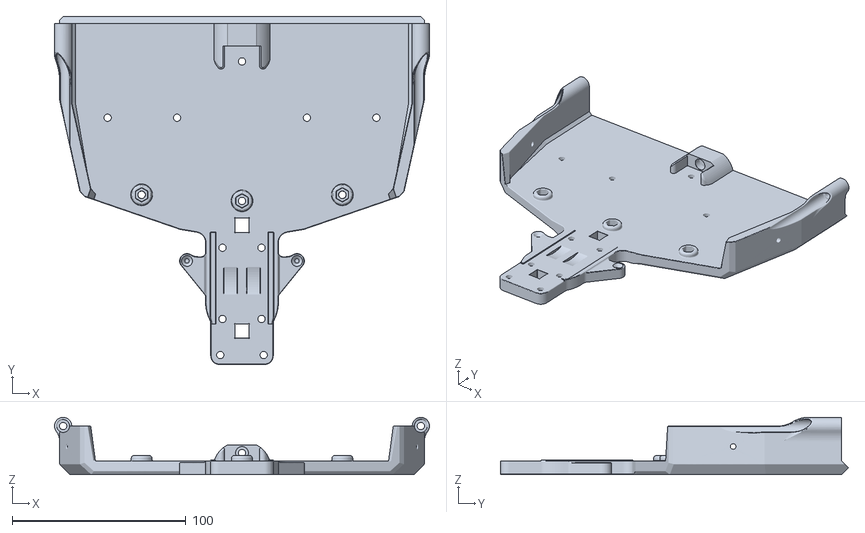
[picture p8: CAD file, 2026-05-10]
instructions/docs/assets/stls/Chassis/Rear_body.stl
216.0 x 200.4 x 33.0

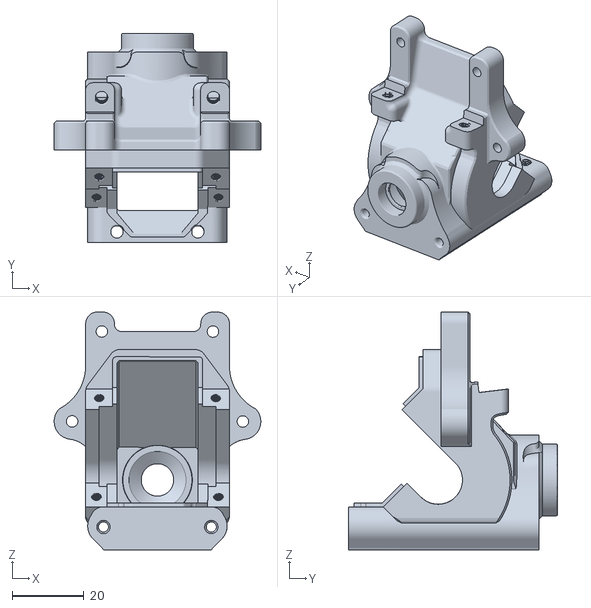
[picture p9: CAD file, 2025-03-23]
instructions/docs/assets/stls/Differential/Front/Diff_body.stl
57.5 x 58.3 x 66.2

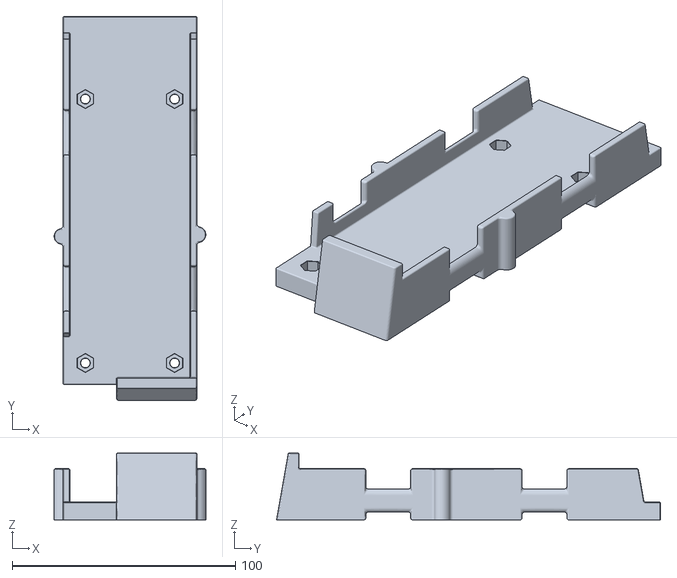
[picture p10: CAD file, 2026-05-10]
instructions/docs/assets/stls/Electronics/Battery_tray_L.stl
68.0 x 172.1 x 30.0

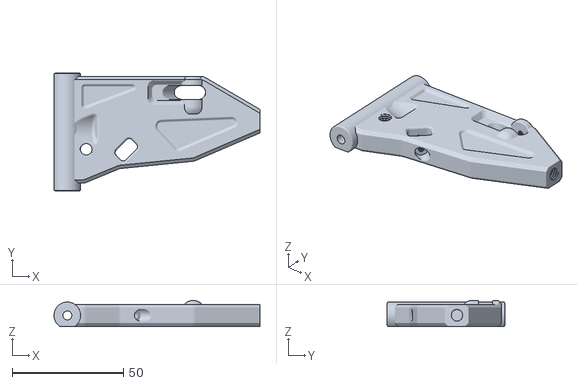
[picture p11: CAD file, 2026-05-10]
instructions/docs/assets/stls/Front-Suspension/Front right arm/Front_arm_bottom_R.stl
92.5 x 52.8 x 11.7

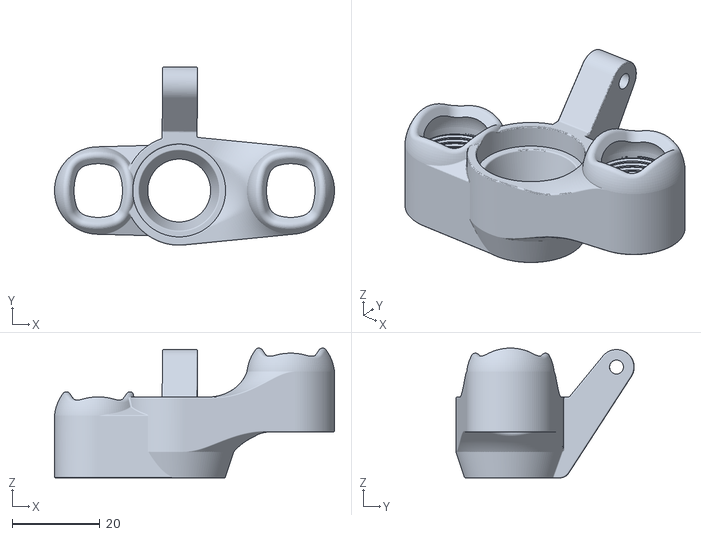
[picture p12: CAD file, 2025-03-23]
instructions/docs/assets/stls/Front-Suspension/Front-Left-Arm/Front_hub_L.stl
64.0 x 40.8 x 29.7

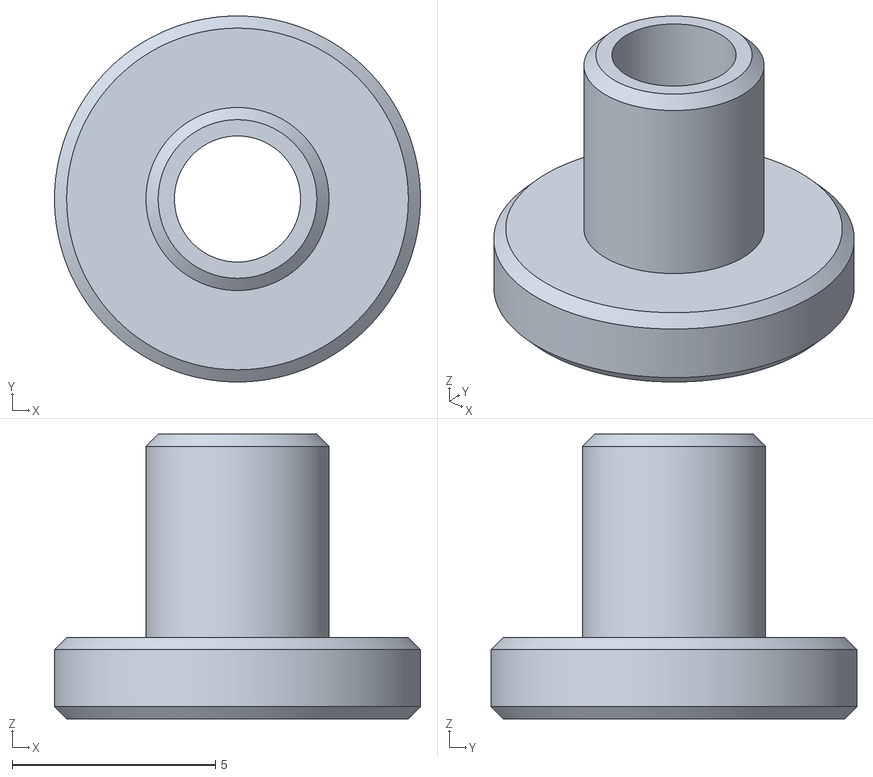
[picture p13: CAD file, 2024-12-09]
instructions/docs/assets/stls/Front-Suspension/Shock_adapter_1_2x.stl
9.00 x 9.00 x 7.00

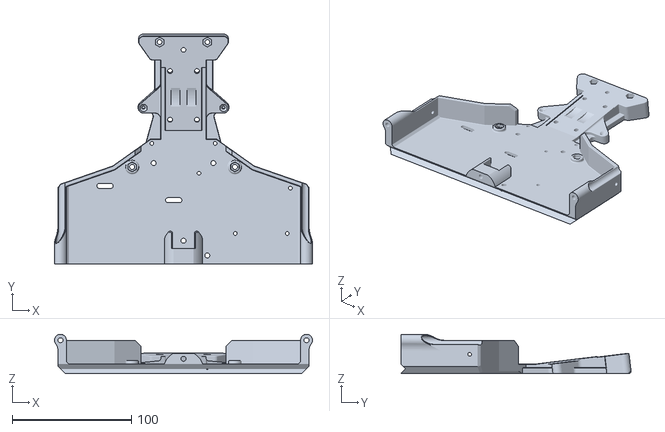
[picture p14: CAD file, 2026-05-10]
instructions/docs/assets/stls/Front_body.stl
216.0 x 193.0 x 33.0

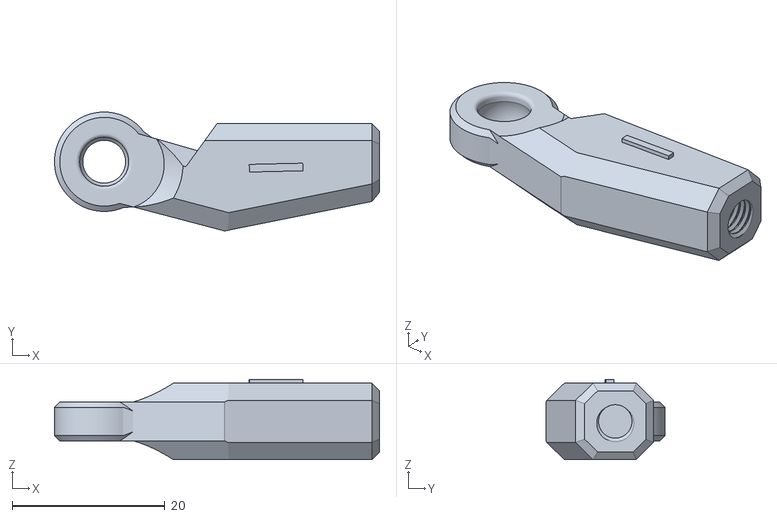
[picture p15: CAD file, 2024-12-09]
instructions/docs/assets/stls/Rear-Suspension/Rear-Left-Arm/Tie_rod_M5_2.stl
42.5 x 15.6 x 10.5

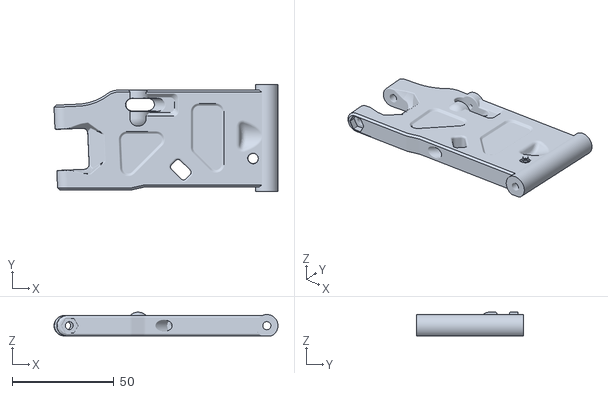
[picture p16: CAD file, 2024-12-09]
instructions/docs/assets/stls/Rear-Suspension/Rear-Right-Arm/Rear_arm_R.stl
110.1 x 52.6 x 11.7

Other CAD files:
instructions/docs/assets/stls/Rear-Suspension/Rear_arm_holder_rear.stl
instructions/docs/assets/stls/Steering/Servo_joint.stl
instructions/docs/assets/stls/Sway-Bar/Front/Sway_bar_joint_x2.stl
instructions/docs/assets/stls/Body-Roll-Cage/Back_Bottom_L.stl
instructions/docs/assets/stls/Body-Roll-Cage/Back_Bottom_R.stl
instructions/docs/assets/stls/Body-Roll-Cage/Back_Cage.stl
instructions/docs/assets/stls/Body-Roll-Cage/Back_Roof.stl
instructions/docs/assets/stls/Body-Roll-Cage/Back_Top_L.stl
instructions/docs/assets/stls/Body-Roll-Cage/Back_Top_R.stl
instructions/docs/assets/stls/Body-Roll-Cage/Front_bumper_L.stl
instructions/docs/assets/stls/Body-Roll-Cage/Front_bumper_R.stl
instructions/docs/assets/stls/Body-Roll-Cage/Front_bumper_bottom.stl
instructions/docs/assets/stls/Body-Roll-Cage/Front_bumper_holder_L.stl
instructions/docs/assets/stls/Body-Roll-Cage/Front_bumper_holder_R.stl
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

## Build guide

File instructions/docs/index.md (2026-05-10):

# StreetBasher: 3D-Printed RC Car Project

**StreetBasher** is an exciting project for radio-controlled car enthusiasts, offering a customizable, 3D-printed RC car. It provides all the resources needed to assemble, modify, and fine-tune your vehicle, including detailed guides, 3D designs, and tuning instructions. Build your StreetBasher and take it for a spin!

---

## Project Resources

### 1. **Build Guide**  
- 📄 [Download the Build Guide](resources.md)  
A detailed, step-by-step manual for assembling your StreetBasher, from start to finish.

### 2. **Bill of Materials (BOM)**  
- 📋 [View the Bill of Materials](bom.md)
A comprehensive list of all the components and materials you'll need for the build.

### 3. **Printed Parts**  
- 🖨️ [Access Printed Part Details](parts.md)  
Specifications and downloadable STL files for the 3D-printed components of the project.

### 4. **SolidWorks Parts**  
- 💻 [Download SolidWorks Files](cad_files.md)  
CAD files for those who want to modify, analyze, or customize the design.

### 5. **3D Tuning Guide**  
- 🔧 [Explore the Tuning Guide](https://ellis3dp.com/Print-Tuning-Guide/articles/index_tuning.html)  
A guide to optimizing your 3D prints for maximum performance and durability.

---

## Ready, Set, Build! 🚗💨  
Unleash your creativity and engineering skills with StreetBasher. Build, customize, and enjoy the thrill of racing your own 3D-printed RC car!

**Source:** [StreetBasher on Printables](https://www.printables.com/model/700706-street-basher-3d-printed-rc-car-17)

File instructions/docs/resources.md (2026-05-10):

# Resources & Downloads

Access all project-related documents, guides, and spreadsheets here. These files provide detailed insights into the building process, bill of materials, and part specifications.

---

## Technical Guides

Detailed assembly instructions and technical specifications for the StreetBasher project.

| File Name | Description | Download |
|---|---|---|
| **Build Guide** | Comprehensive step-by-step assembly manual. | [:material-file-pdf: PDF](assets/documents/Build_Guide_StreetBASHER.pdf) |
| **Technical Guide** | Quick reference and technical specifications. | [:material-file-pdf: PDF](assets/documents/guide.pdf) |

---

## Project Spreadsheets

Managed lists for parts, procurement, and planning.

| File Name | Description | Download |
|---|---|---|
| **BOM Parts List** | Complete Bill of Materials including hardware and electronics. | [:material-file-excel: XLSX](assets/documents/BOM_parts_StreetBASHER.xlsx) |
| **Printed Parts List** | Organized list of all 3D-printable components. | [:material-file-excel: XLSX](assets/documents/Printed_parts_StreetBASHER.xlsx) |

---

## External Resources

- [Official Printables Project Page](https://www.printables.com/model/700706-street-basher-3d-printed-rc-car-17)
- [GitHub Repository](https://github.com/CagriCatik/StreetBasher)

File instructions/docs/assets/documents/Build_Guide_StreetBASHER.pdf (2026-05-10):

# BUILD GUIDE

# StreetBASHER

## Technical specification

682 mm

404 mm

310 mm

136 mm roof

152 mm + wing

# StreetBASHER

## Calibration

1. Tune your printer Link (https://ellis3dp.com/Print-Tuning-Guide/articles/index_tuning.html)
2. Print Fit_test.stl models and check dimensions and bearing fit test
3. If all dimensions are accurate except for the holes, you will need to compensate for this in the slicer changing Hole Horizontal Expansion (Cura) or Hole Sizes Compensation (SS).
4. Print once again and repeat.

### Bearings should be inserted with a some force, they must not be loose

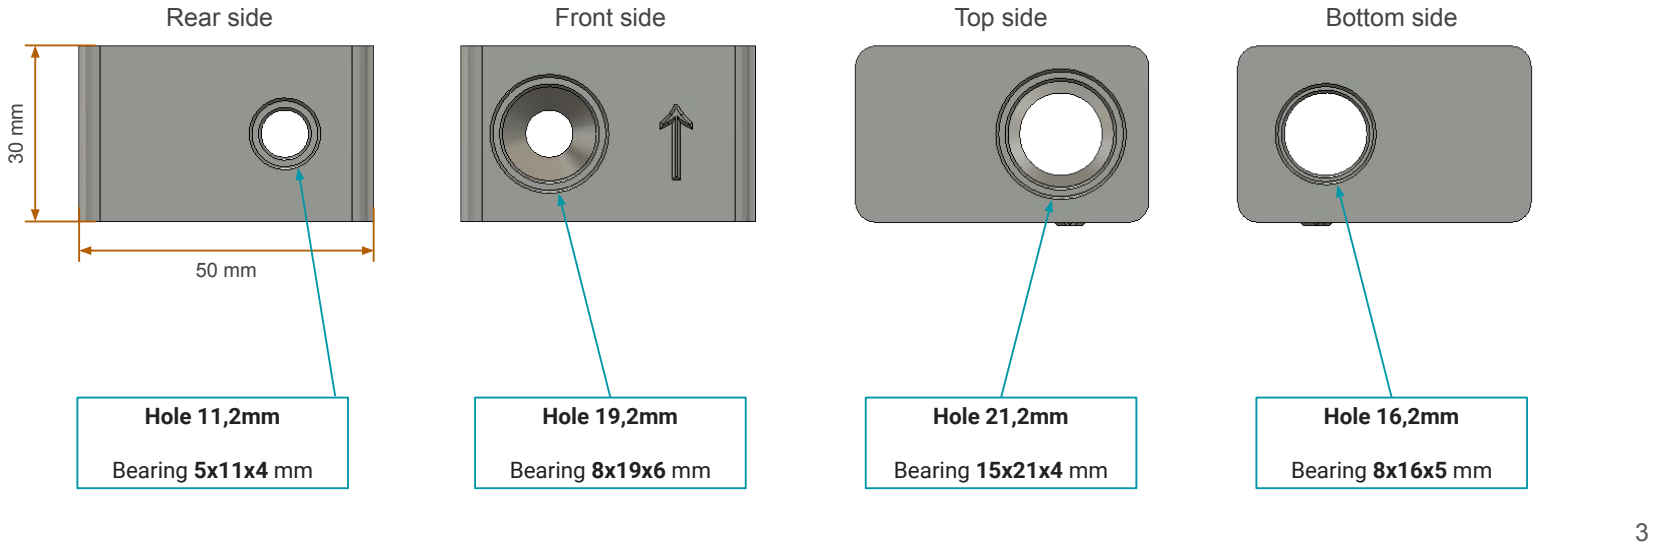
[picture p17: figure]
Rear side; Front side; Top side; Bottom side; Hole 11,2mm; Bearing 5x11x4 mm; Hole 19,2mm; Bearing 8x19x6 mm; Hole 21,2mm; Bearing 15x21x4 mm; Hole 16,2mm; Bearing 8x16x5 mm

# StreetBASHER

## Chassis - Main

2x SHCS M4x30mm

SHCS M4x20mm

2x SHCS M4x30mm

SHCS M4x20mm

6x M4 Hex nut

Front_body.stl | Center_body.stl | Rear_body.stl

# StreetBASHER

## Chassis - Main

4x M4 Hex nut

Front_brace.stl | Rear_brace.stl

# StreetBASHER

## Chassis - Main

2x SHCS M4x16mm

# StreetBASHER

## Chassis - Main

2x FHCS M3x6mm

2x M4 Hex nut

! Careful !
Screwing into plastic, do not overtighten.

# StreetBASHER

## Chassis - Main

2x FHCS M3x6mm

3x M4 Hex nut

! Careful !
Screwing into plastic, do not overtighten.

# StreetBASHER

## Chassis - Electronics

# StreetBASHER

## Chassis - Electronics

4x SHCS M4x12mm | 4x SHCS M3x25mm

4x SHCS M4x12mm

! Careful !
Screwing into plastic, do not overtighten.

# StreetBASHER

## Chassis - Electronics

Use strips of foam padding to prevent the battery from
damaging

# StreetBASHER

## Electronics - Ele.box

! Careful !
Screwing into plastic, do not overtighten.
2x SHCS M3x30mm | 2x SHCS M3x18mm

M4 Hex nut

Ele_box_body_WP8BL150.stl

Servo + 25T arm

Receiver

If you have ESC without
screw holes for mounting,
use Ele_box_body_ESC.stl
and secure the esc with zip ties.
And attach On / Off switch to Ele_cover.stl with double
sided tape.

# StreetBASHER

## Electronics - Ele.box

Use strips of foam padding to fill these spaces to achieve some waterproofing.
Shape of the foam should look like this:

Route servo cables under
servo and then this way into receiver box

# StreetBASHER

## Electronics - Ele.box

! Careful !
Screwing into plastic, do not overtighten.

4x SHCS M3x16mm

SHCS M3x8mm

Ele_cover.stl

On_Off_switch_holder_WP8BL150.stl

Receiver antenna tube

# StreetBASHER

## Electronics - Ele.box

ESC 150A

Use strips of foam padding under ESC to help with shock absorption

# StreetBASHER

## Electronics - Ele.box

4x SHCS M3x8mm

# StreetBASHER

## Chassis - Electronics

Ele. box assembly

# StreetBASHER

## Chassis - Electronics

4x SHCS M3x10mm

SHCS M3x14mm

SHCS M3x25mm

SHCS M4x30mm

! Careful !
Screwing into plastic, do not overtighten.

# StreetBASHER

## Rear assembly - Diff

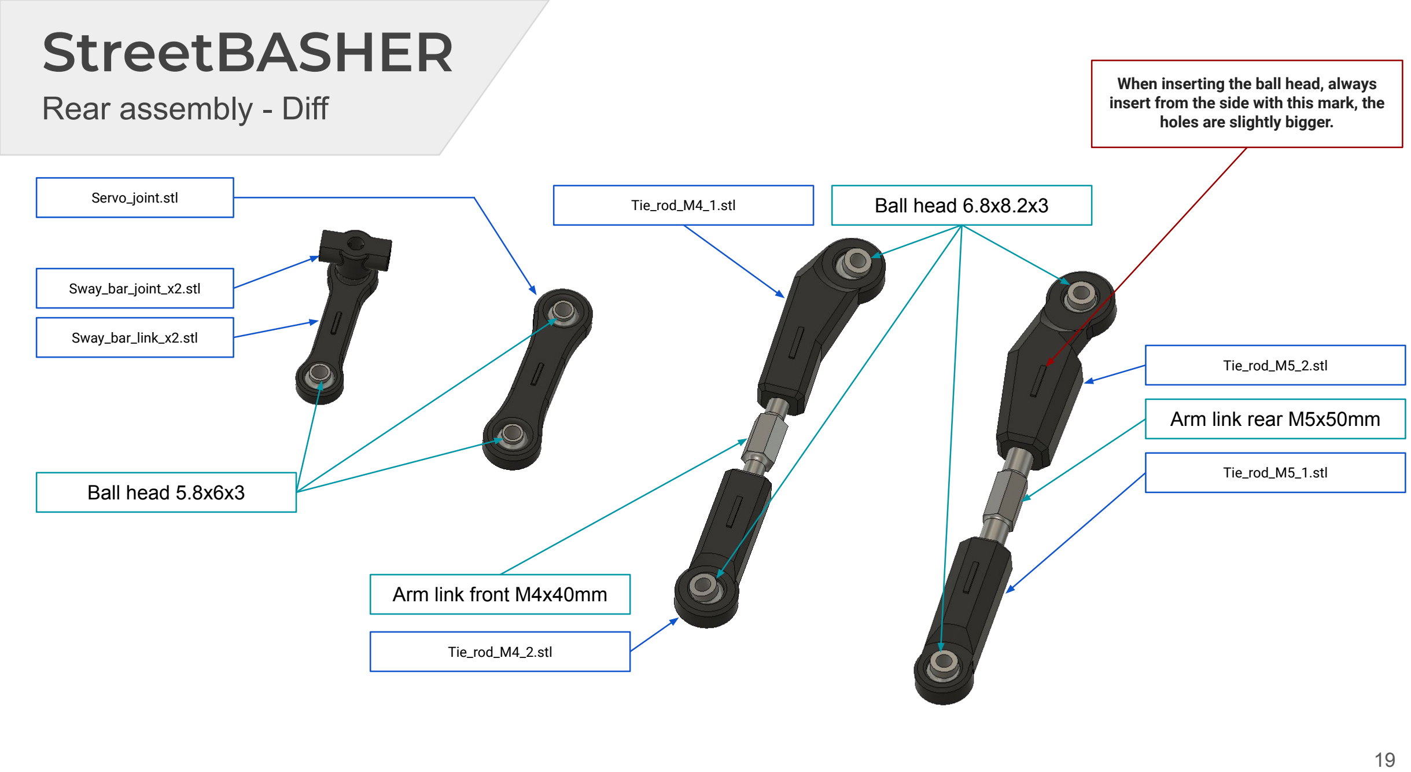
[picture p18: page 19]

Arm link front M4x40mm

Arm link rear M5x50mm

Tie_rod_M5_2.stl

Ball head 5.8x6x3

Ball head 6.8x8.2x3

Tie_rod_M5_1.stl

Tie_rod_M4_2.stl

Tie_rod_M4_1.stl Servo_joint.stl

Sway_bar_joint_x2.stl

Sway_bar_link_x2.stl

When inserting the ball head, always insert from the side with this mark, the holes are slightly bigger.

# StreetBASHER

## Rear assembly - Diff

Differential 43T

Pinion 13T

Bearing 8x19x6 mm

Bearing 5x11x4 mm

Diff_body.stl

# StreetBASHER

## Rear assembly - Diff

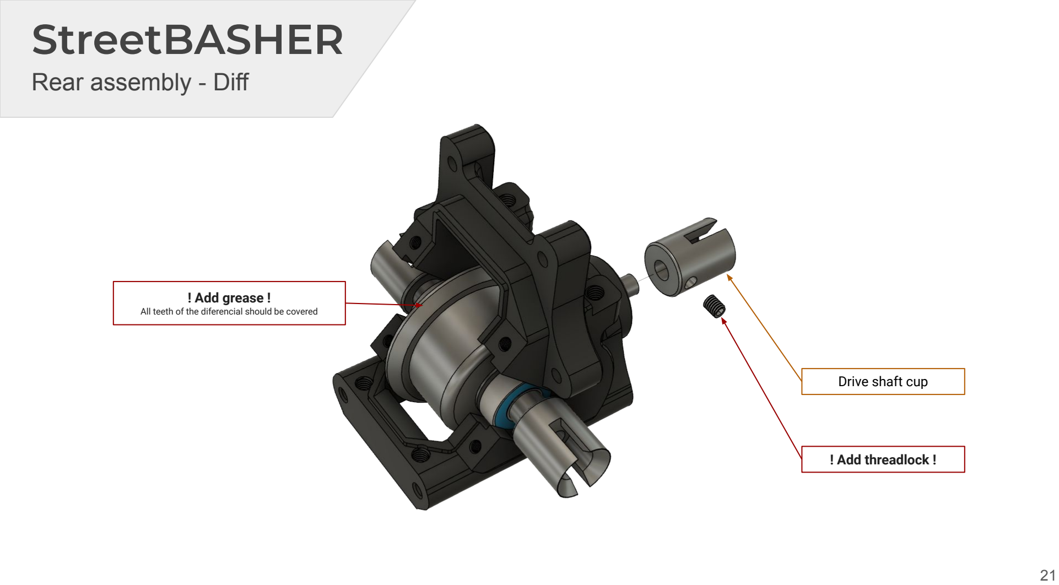
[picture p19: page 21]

Drive shaft cup

! Add threadlock !

! Add grease !
All teeth of the diferencial should be covered

Screwing into plastic, do not overtighten.

# StreetBASHER

## Rear assembly - Main

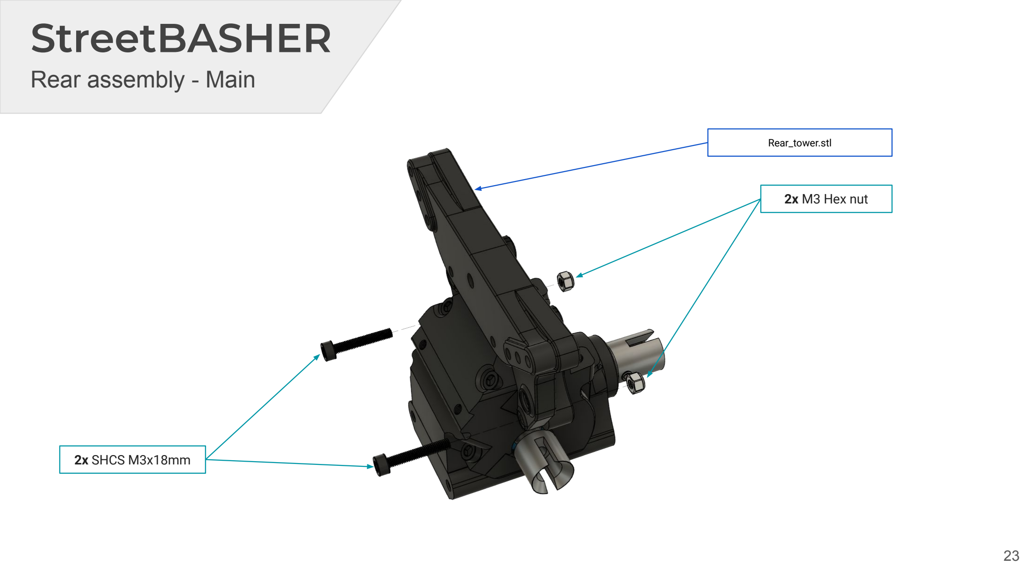
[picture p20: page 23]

2x SHCS M3x18mm

Rear_tower.stl

2x M3 Hex nut

# StreetBASHER

## Rear assembly - Main

2x SHCS M3x30mm

Rear_arm_holder_rear.stl

Rear_arm_holder_front.stl

2x SHCS M3x30mm

! Careful !
Screwing into plastic, do not overtighten.

# StreetBASHER

## Rear assembly - Right Arm

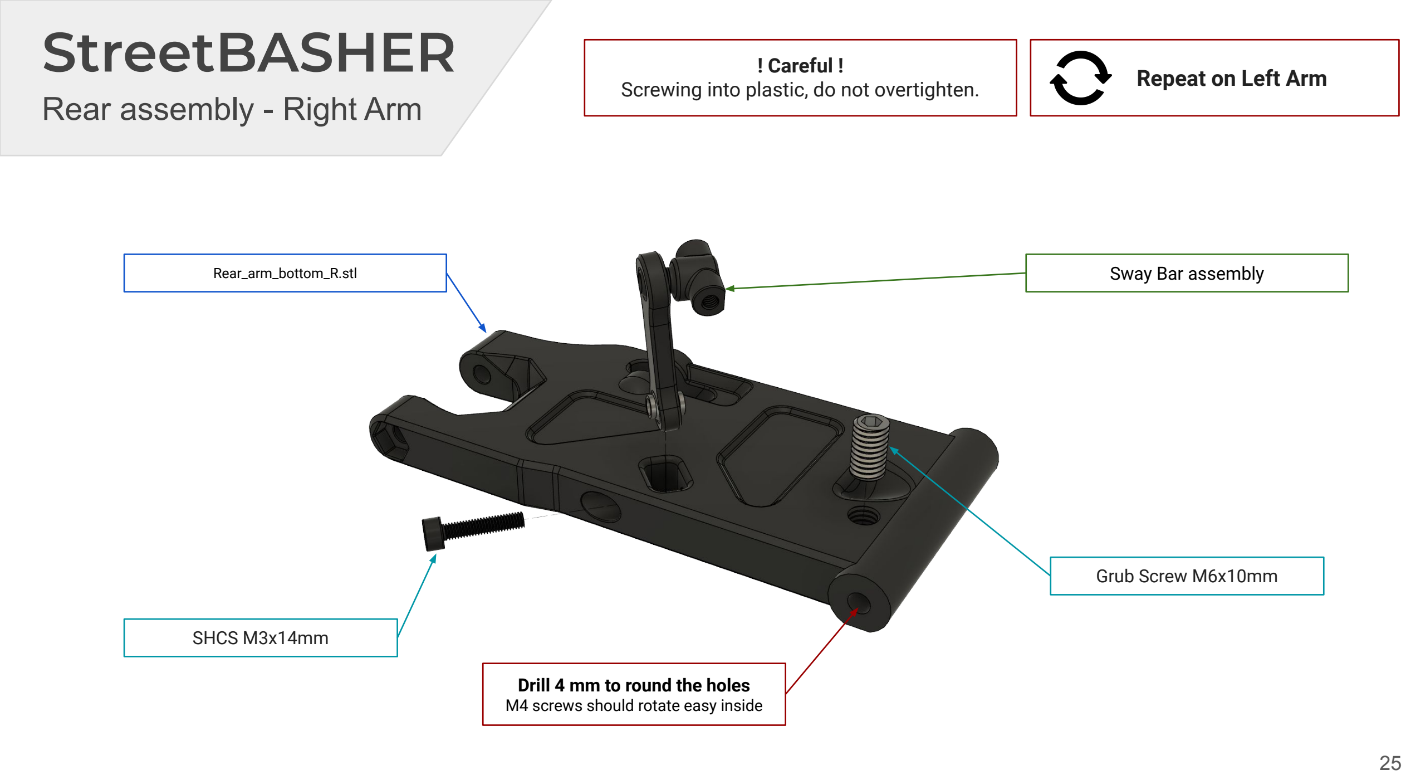
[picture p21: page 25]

SHCS M3x14mm

! Careful !
Screwing into plastic, do not overtighten.

Rear_arm_bottom_R.stl

### Repeat on Left Arm

Grub Screw M6x10mm

Sway Bar assembly

Drill 4 mm to round the holes M4 screws should rotate easy inside

# StreetBASHER

## Rear assembly - Main

2x SHCS M4x70mm

! Careful !
Screwing into plastic, do not overtighten.

Rear_arm_bottom_R.stl

Rear_arm_bottom_L.stl

# StreetBASHER

## Rear assembly - Main

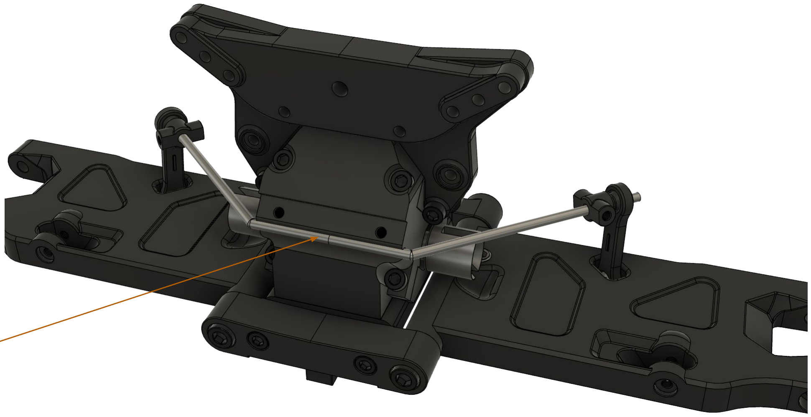
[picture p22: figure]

Swaybar rear

# StreetBASHER

## Rear assembly - Main

2x M3x5mm Grub Screw

2x SHCS M3x10mm

Diff_sway_bar_cover.stl

2x M3x5mm Grub Screw

! Careful !
Screwing into plastic, do not overtighten.

# StreetBASHER

## Rear assembly - Right Arm

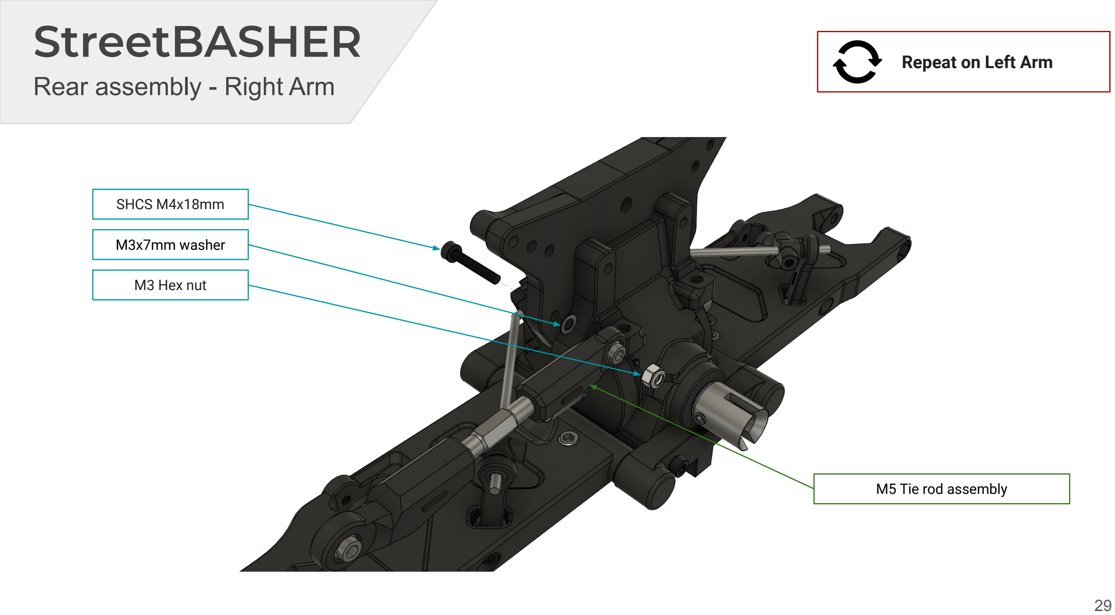
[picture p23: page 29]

SHCS M4x18mm

M3x7mm washer

M3 Hex nut

M5 Tie rod assembly

### Repeat on Left Arm

# StreetBASHER

## Rear assembly - Right Arm

Rear_hub_R.stl

Bearing 8x16x5 mm

Bearing 15x21x4 mm

CVD driveshaft Rear

### Repeat on Left Arm

Drill 4 mm to round the holes M4 screws should rotate easy inside

# StreetBASHER

## Rear assembly - Right Arm

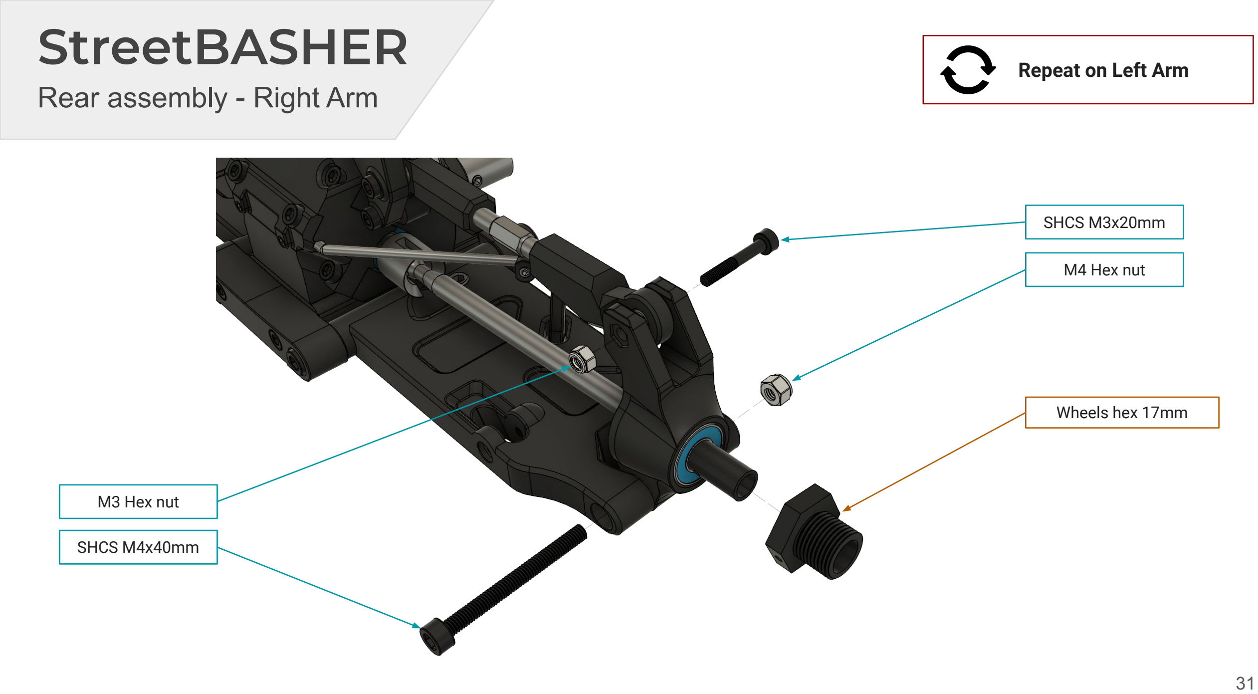
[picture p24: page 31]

### Repeat on Left Arm

Wheels hex 17mm

M3 Hex nut

SHCS M4x40mm

M4 Hex nut

SHCS M3x20mm

# StreetBASHER

## Rear assembly - Right Arm

### Repeat on Left Arm

Grub screw from front wheel axle

Pin from wheel hex

# StreetBASHER

## Rear assembly - Right Arm

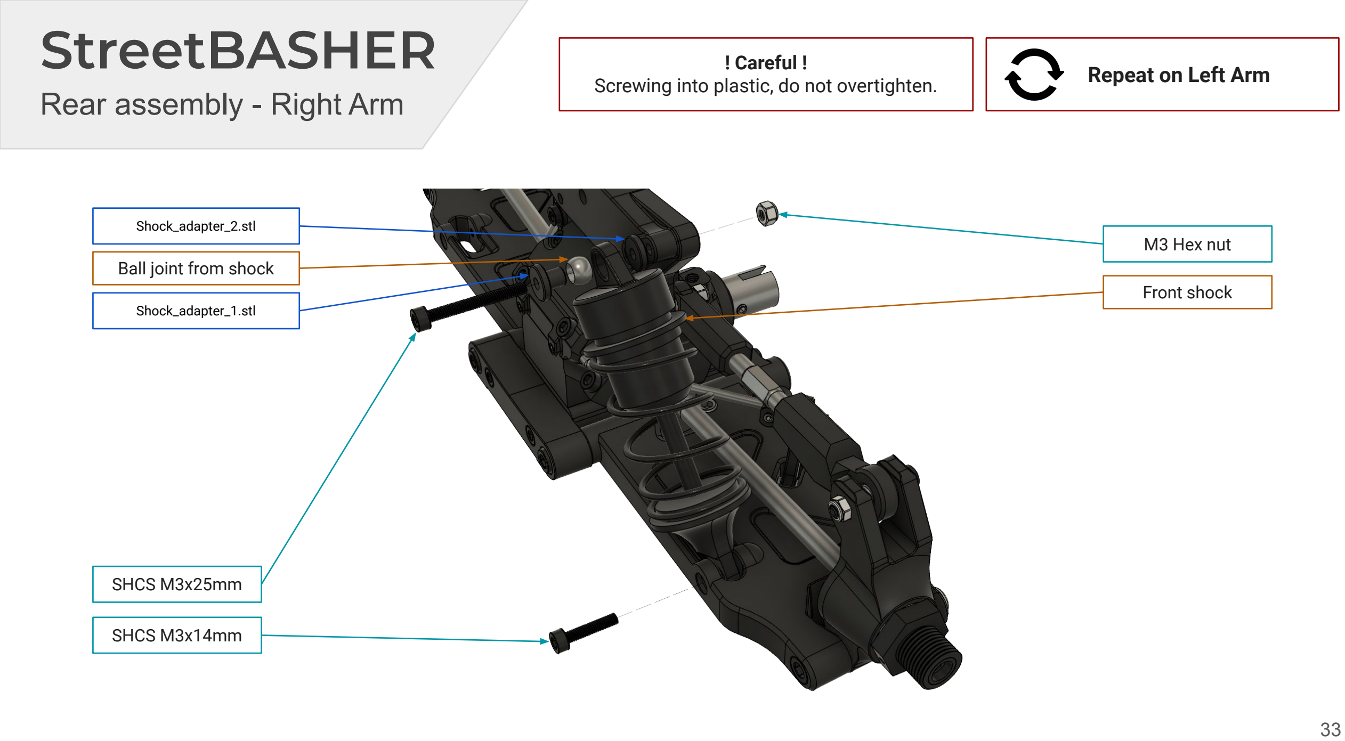
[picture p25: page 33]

### Repeat on Left Arm ! Careful !

Screwing into plastic, do not overtighten.

Front shock

M3 Hex nut

SHCS M3x14mm

SHCS M3x25mm

Shock_adapter_2.stl

Shock_adapter_1.stl

Ball joint from shock

# StreetBASHER

## Rear assembly - Complete

# StreetBASHER

## Chassis - Rear assembly

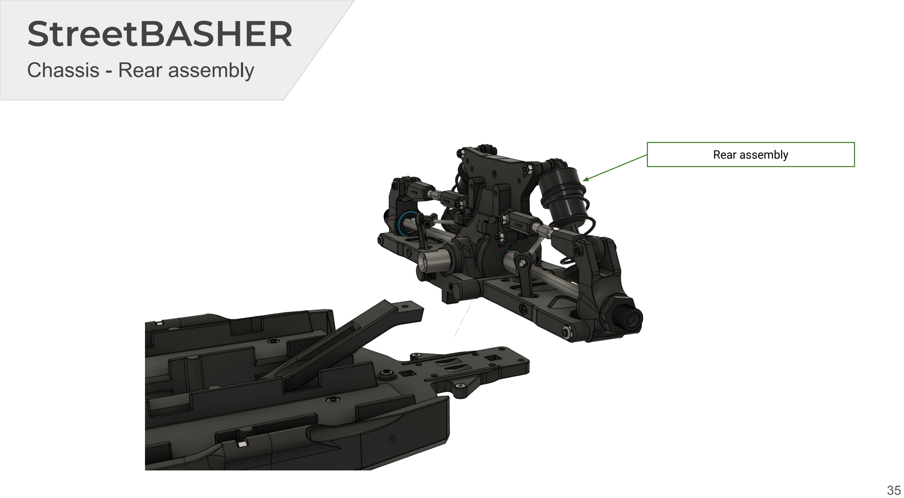
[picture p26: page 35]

Rear assembly

# StreetBASHER

## Chassis - Rear assembly

2x SHCS M4x16mm

2x SHCS M4x12mm

! Careful !
Screwing into plastic, do not overtighten.

# StreetBASHER

## Chassis - Steering

2x SHCS M4x55mm

# StreetBASHER

## Steering - Main

M3 Hex nut

Servo_saver_to_link.stl

Servo_saver_top.stl

Right_tower_upper.stl

Ríght_tower_lower.stl

Servo saver Spring

# StreetBASHER

## Steering - Main

Bearing 3x6x2.5 mm flange

Steering_shaft_x4.stl

Steering_shaft_x4.stl

Left_shaft_arm.stl

# StreetBASHER

## Steering - Main

# StreetBASHER

## Steering - Main

M3x7mm washer

SHCS M3x14mm

M3 Hex nut

M4 Tie rod assembly

### Repeat on other side

# StreetBASHER

## Steering - Complete

# StreetBASHER

## Chassis - Steering

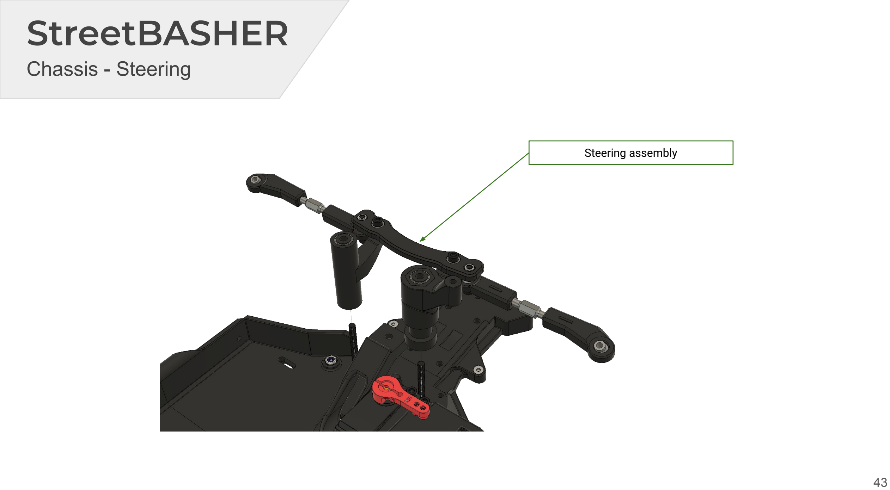
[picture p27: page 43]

Steering assembly

# StreetBASHER

## Chassis - Steering

SHCS M3x16mm

M3x7mm washer

SHCS M3x10mm

Steering link assembly

# StreetBASHER

## Front assembly - Diff

Differential 43T

Pinion 13T

Bearing 8x19x6 mm

Bearing 5x11x4 mm

Diff_body.stl

# StreetBASHER

## Front assembly - Diff

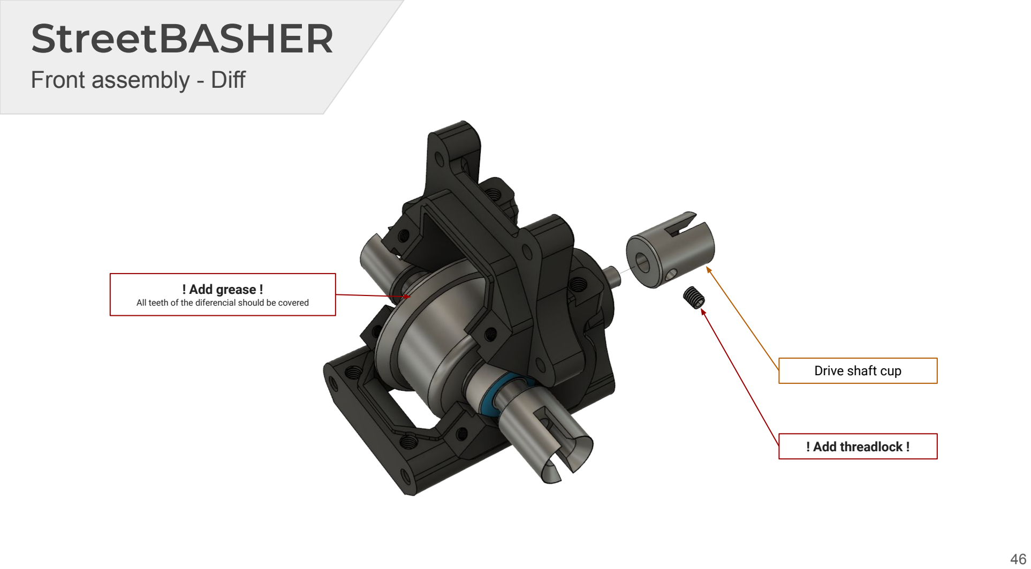
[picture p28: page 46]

Drive shaft cup

! Add threadlock !

! Add grease !
All teeth of the diferencial should be covered

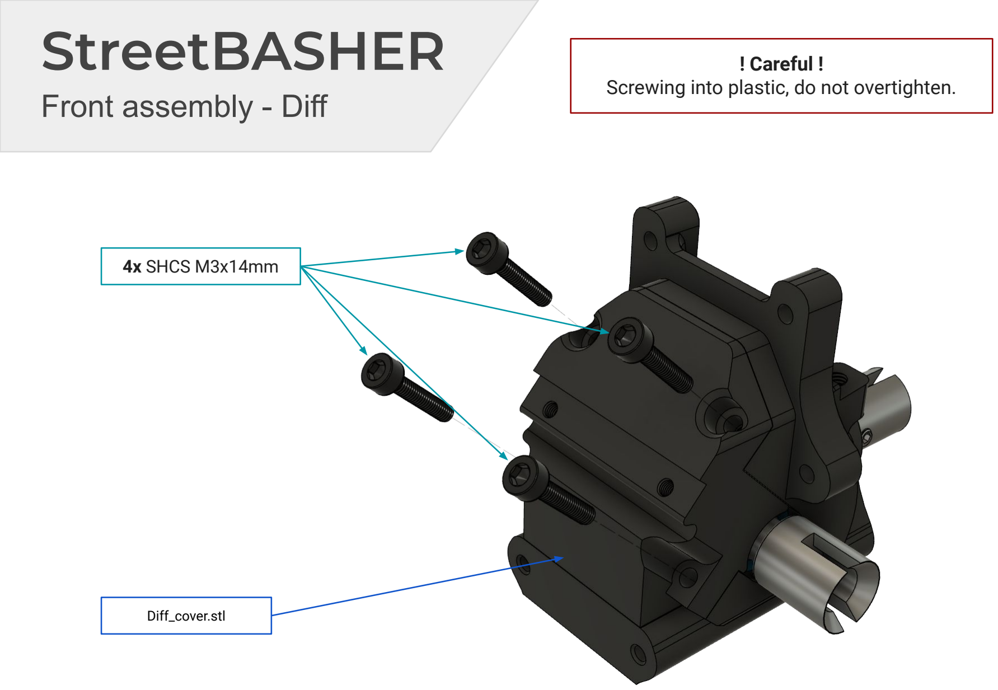
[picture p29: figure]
StreetBASHER; Front assembly - Diff; 4x SHCS M3x14mm; Diff_cover.stl; ! Careful !

Screwing into plastic, do not overtighten.

# StreetBASHER

## Front assembly - Main

2x SHCS M3x18mm

Front_tower.stl

2x M3 Hex nut

# StreetBASHER

## Front assembly - Main

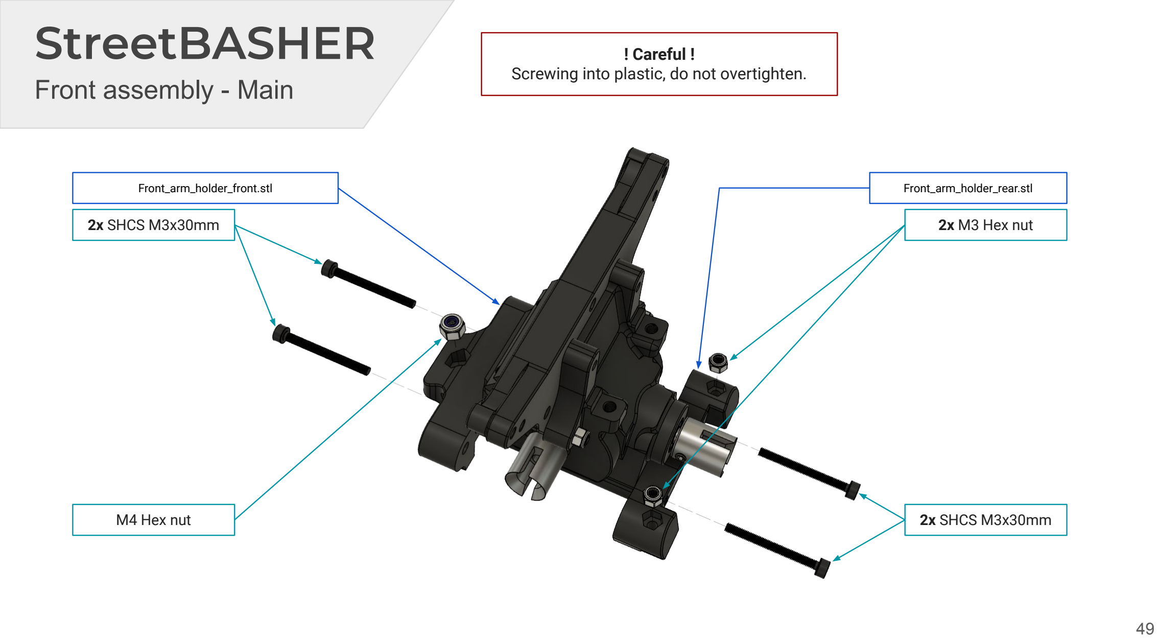
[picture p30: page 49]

2x SHCS M3x30mm

Front_arm_holder_rear.stl

2x M3 Hex nut

Front_arm_holder_front.stl

M4 Hex nut | 2x SHCS M3x30mm

! Careful !
Screwing into plastic, do not overtighten.

# StreetBASHER

## Front assembly - Main

Use temporary screws to hold in place M3x10mm and M4x16mm

Top_plate.stl

2x M3 Hex nut

! Careful !
Screwing into plastic, do not overtighten.

Top_arm_holder.stl

# StreetBASHER

## Front assembly - Left Arm

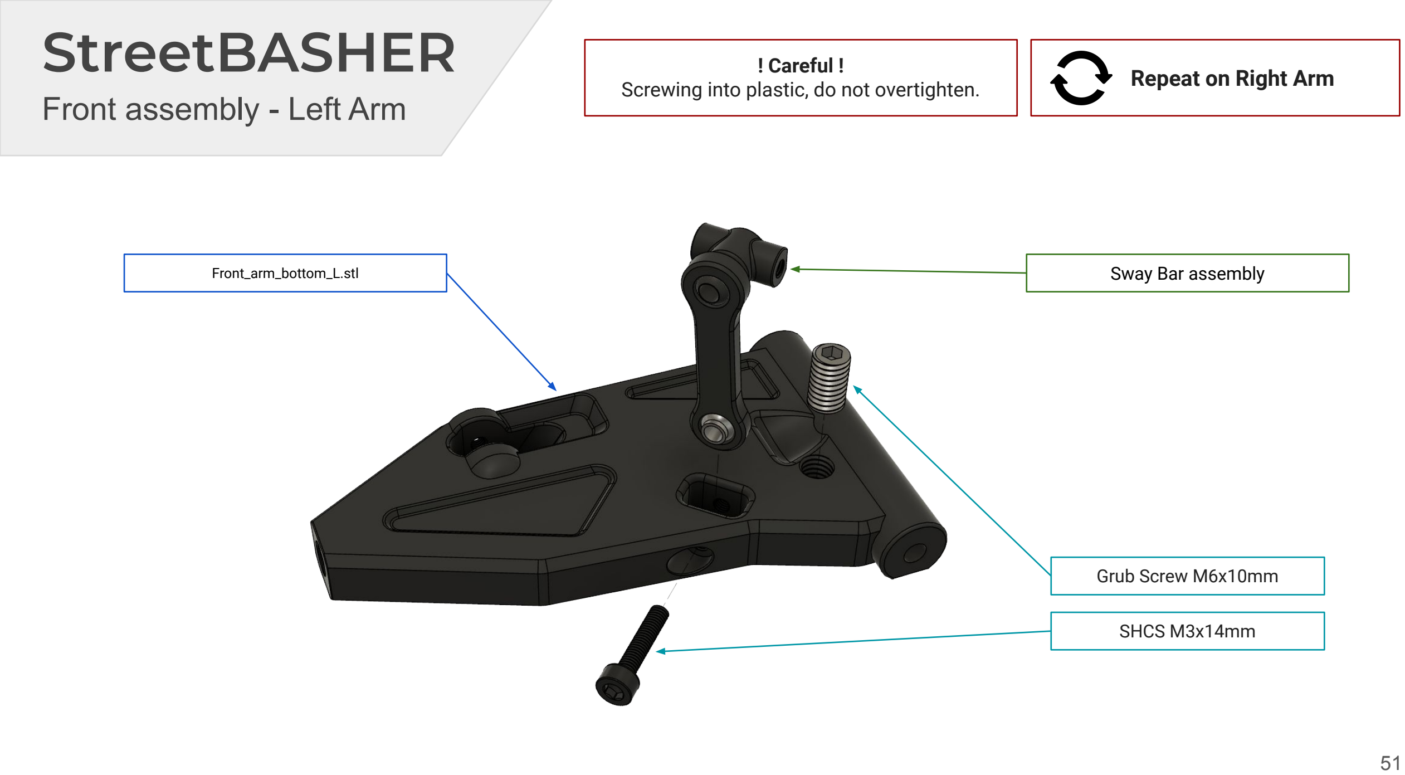
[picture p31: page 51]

SHCS M3x14mm

! Careful !
Screwing into plastic, do not overtighten.

Front_arm_bottom_L.stl

### Repeat on Right Arm

Grub Screw M6x10mm

Sway Bar assembly

# StreetBASHER

## Front assembly - Left Arm

### Repeat on Right Arm

Drill 4 mm to round the holes M4 screws should rotate easy inside

Front_arm_top_L.stl

Front_arm_bottom_L.stl

# StreetBASHER

## Front assembly - Main

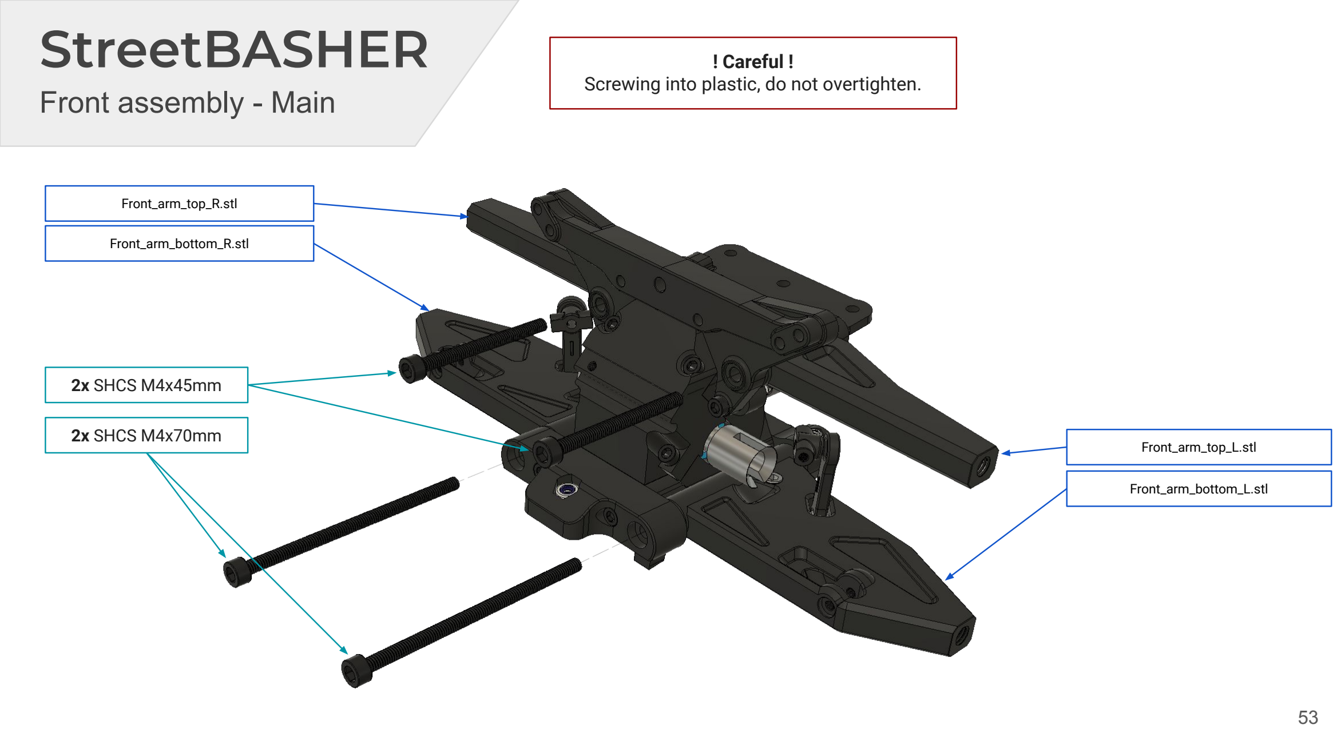
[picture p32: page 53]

2x SHCS M4x70mm

! Careful !
Screwing into plastic, do not overtighten.

Front_arm_bottom_L.stl

2x SHCS M4x45mm

Front_arm_top_L.stl

Front_arm_top_R.stl

Front_arm_bottom_R.stl

# StreetBASHER

## Front assembly - Main

Swaybar front

# StreetBASHER

## Front assembly - Main

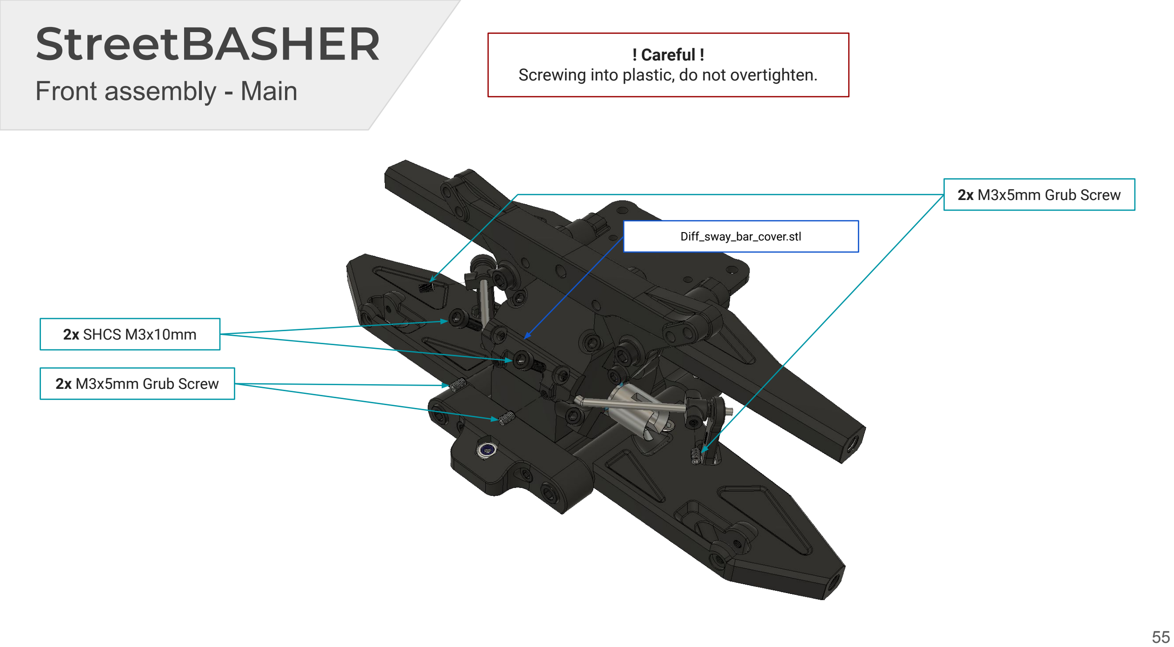
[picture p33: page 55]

2x M3x5mm Grub Screw

! Careful !
Screwing into plastic, do not overtighten.

2x SHCS M3x10mm

Diff_sway_bar_cover.stl

2x M3x5mm Grub Screw

# StreetBASHER

## Front assembly - Left Arm

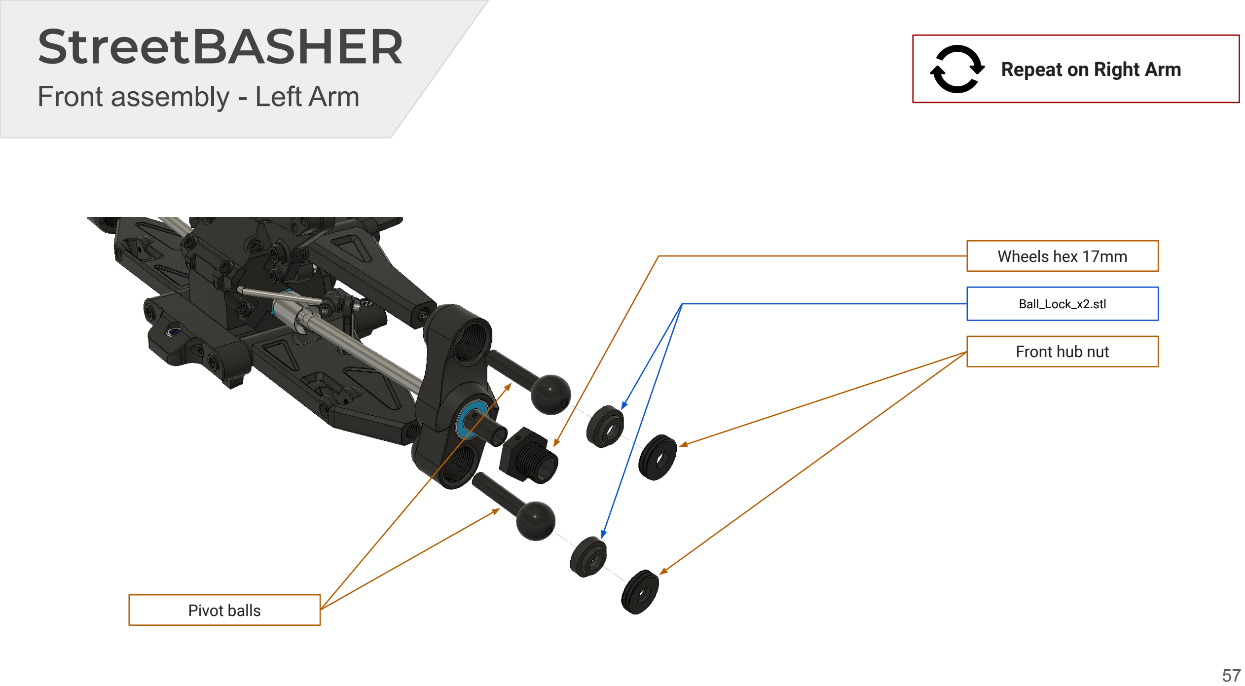
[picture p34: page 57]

Ball_Lock_x2.stl

### Repeat on Right Arm

Pivot balls

Front hub nut

Wheels hex 17mm

# StreetBASHER

## Front assembly - Left Arm

### Repeat on Right Arm

Grub screw from front wheel axle

Pin from wheel hex

# StreetBASHER

## Front assembly - Left Arm

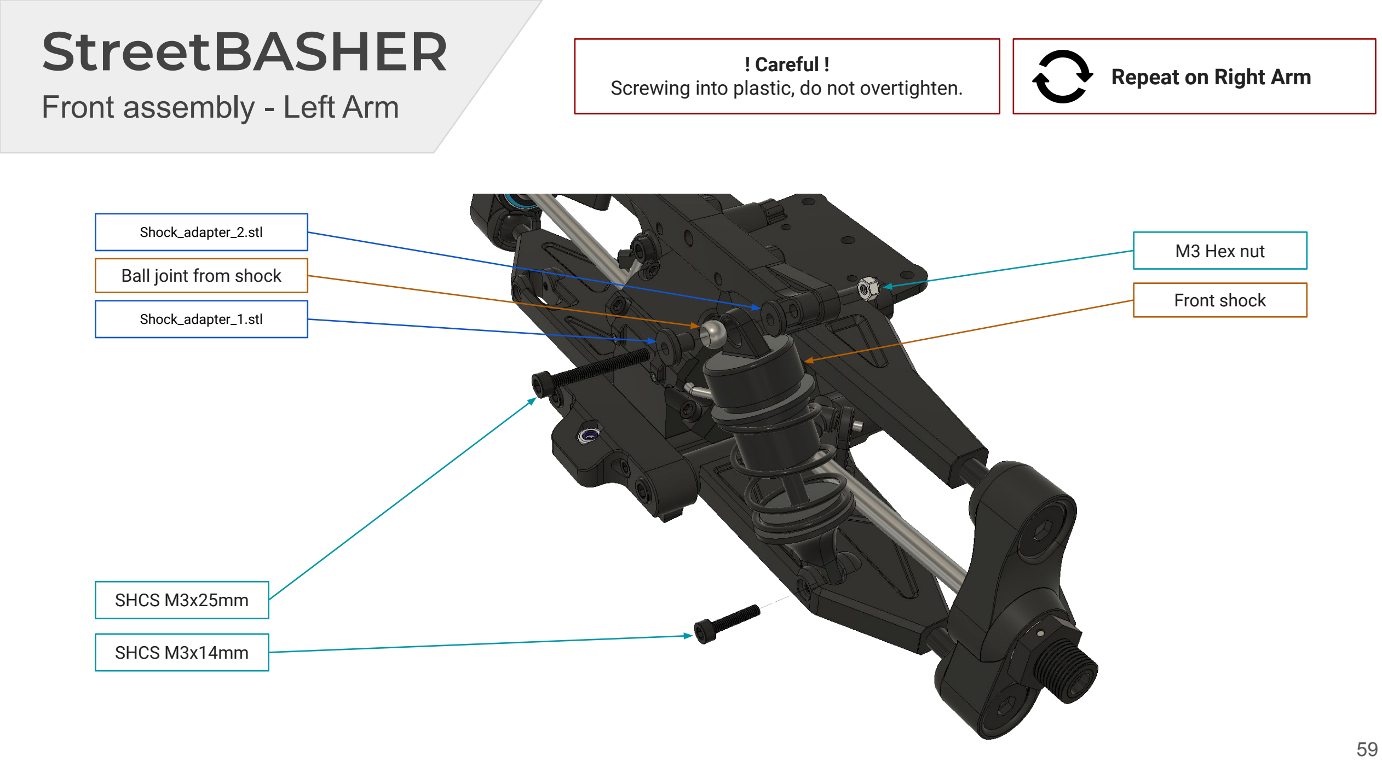
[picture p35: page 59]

### Repeat on Right Arm

Front shock

M3 Hex nut

SHCS M3x14mm

SHCS M3x25mm

Shock_adapter_2.stl

Shock_adapter_1.stl

Ball joint from shock

! Careful !
Screwing into plastic, do not overtighten.

# StreetBASHER

## Front assembly - Complete

# StreetBASHER

## Chassis - Front assembly

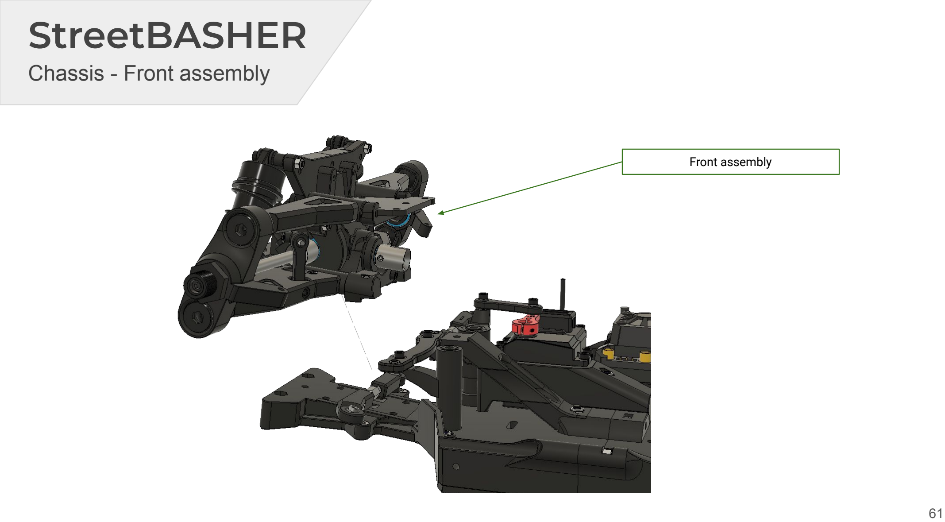
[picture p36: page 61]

Front assembly

# StreetBASHER

## Chassis - Front assembly

! Careful !
Screwing into plastic, do not overtighten.

2x SHCS M3x16mm

3x SHCS M4x20mm | 2x SHCS M4x12mm

# StreetBASHER

## Steering - Left Arm

SHCS M4x18mm

M3x7mm washer

M3 Hex nut

### Repeat on Right Arm

# StreetBASHER

## Chassis - Steering

2x M4 Hex nut

# StreetBASHER

## Chassis - Center drive

4x SHCS M4x70mm

# StreetBASHER

## Center drive - Motor

6x SHCS M3x14mm

Motor_support_mount_3.stl

3x M4 Hex nut

Motor_support_mount_1.stl

Motor_support_mount_2.stl

Motor 4092 + Heatsink

Fan_shroud.stl

# StreetBASHER

## Center drive - Motor

2x SHCS M3x10mm
Don’t tight them, motor
should be able to slide

2x M3x7mm washer

Pinion gear 19T - 27T
Align with teeth of the
center differential, so they engage fully

! Add threadlock !
To the grub screw of the
pinion

Center_diff_bottom.stl

# StreetBASHER

## Chassis - Center drive

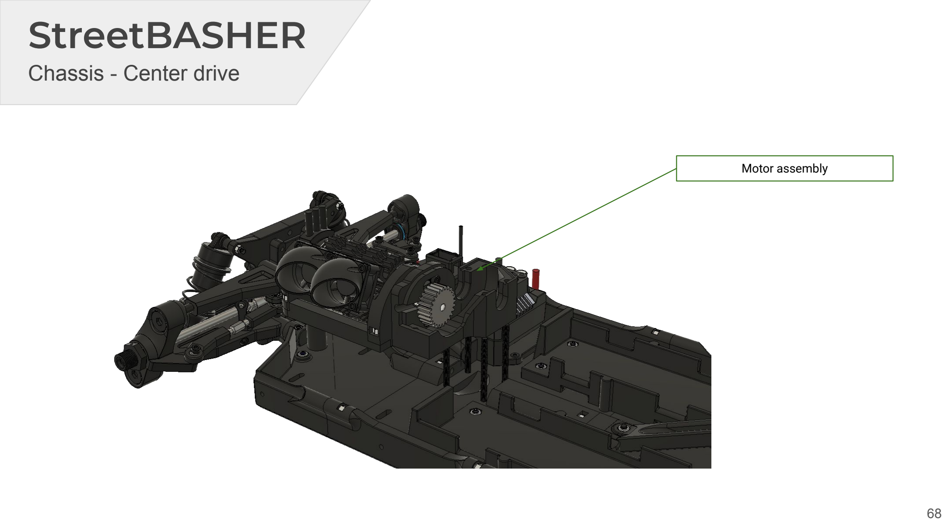
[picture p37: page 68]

Motor assembly

# StreetBASHER

## Chassis - Center drive

Driveshaft 103.5mm | Differential 46T | Driveshaft 170mm

# StreetBASHER

## Chassis - Center drive

Center_diff_top.stl

# StreetBASHER

## Chassis - Center drive

2x SHCS M4x20mm; SHCS M4x12mm; Don’t tight them, motor should be able to slide

# StreetBASHER

## Chassis - Center drive

Center_diff_top_cover.stl

M4 Hex nut

! GEAR MESH !
Insert a piece of standard notebook paper between the pinion and diff gear before you slide the motor assembly into place, squeezing the paper between the pinion and diff gear. Tighten the motor screws and screws from the bottom down, pull the paper out and you should have a perfect gear mesh

SHCS M4x45mm

# StreetBASHER

## Chassis - Front bumper

Center_Front_bumper.stl

2x M4 Hex nut

6x M3 Hex nut

# StreetBASHER

## Chassis - Front bumper

2x FHCS M4x20mm

2x FHCS M4x16mm | 6x FHCS M3x12mm

Front_spliter.stl

# StreetBASHER

## Chassis - Center brace

4x M4 Hex nut

Front_center_brace_holder.stl

Center_brace_holder.stl

Rear_brace_holder.stl

Carbon center brace
15x15x13mm
Cut to 365mm

# StreetBASHER

## Chassis - Center brace

Remove temporary M4 screws

Center brace

# StreetBASHER

## Chassis - Center brace

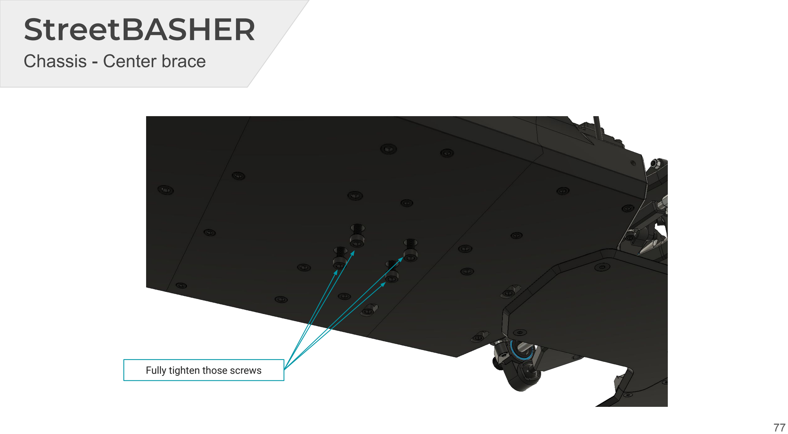
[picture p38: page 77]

Fully tighten those screws

# StreetBASHER

## Chassis - Center brace

SHCS M4x30mm

SHCS M4x30mm
Before screwing, drill 4mm hole through carbon fiber tube

2x SHCS M4x16mm

M4 Hex nut

! Careful !
Screwing into plastic, do not overtighten.

# StreetBASHER

## Chassis - Center brace

! Careful !
Screwing into plastic, do not overtighten.

# StreetBASHER

## Chassis - Front bumper

2x SHCS M3x30mm

2x M3 Hex nut

Front body brace

# StreetBASHER

## Chassis - Front bumper

2x M4 Hex nut

2x SHCS M4x20mm

# StreetBASHER

## Chassis - Rear diffuser

2x M4 Hex nut

Rear_difuser_body.stl

# StreetBASHER

## Chassis - Rear diffuser

2x FHCS M4x20mm

3x FHCS M4x16mm

# StreetBASHER

## Chassis - Rear diffuser

2x SHCS M3x30mm

2x M3 Hex nut

Rear_wing_brace_R.stl

Rear_wing_brace_L.stl

# StreetBASHER

## Chassis - Rear diffuser

2x FHCS M4x16mm

2x M4 Hex nut

# StreetBASHER

## Chassis - Wing

4x FHCS M3x14mm

2x M4 Hex nut

4x M3 Hex nut

Wing_mount.stl

# StreetBASHER

## Chassis - Wing

2x FHCS M4x16mm

3x FHCS M3x16mm

3x FHCS M3x16mm

! Careful !
Screwing into plastic, do not overtighten.

Side_wing_L.stl

Side_wing_R.stl

Wing_body.stl

# StreetBASHER

## Body Roll Cage

! Careful !
Screwing into plastic, do not overtighten.

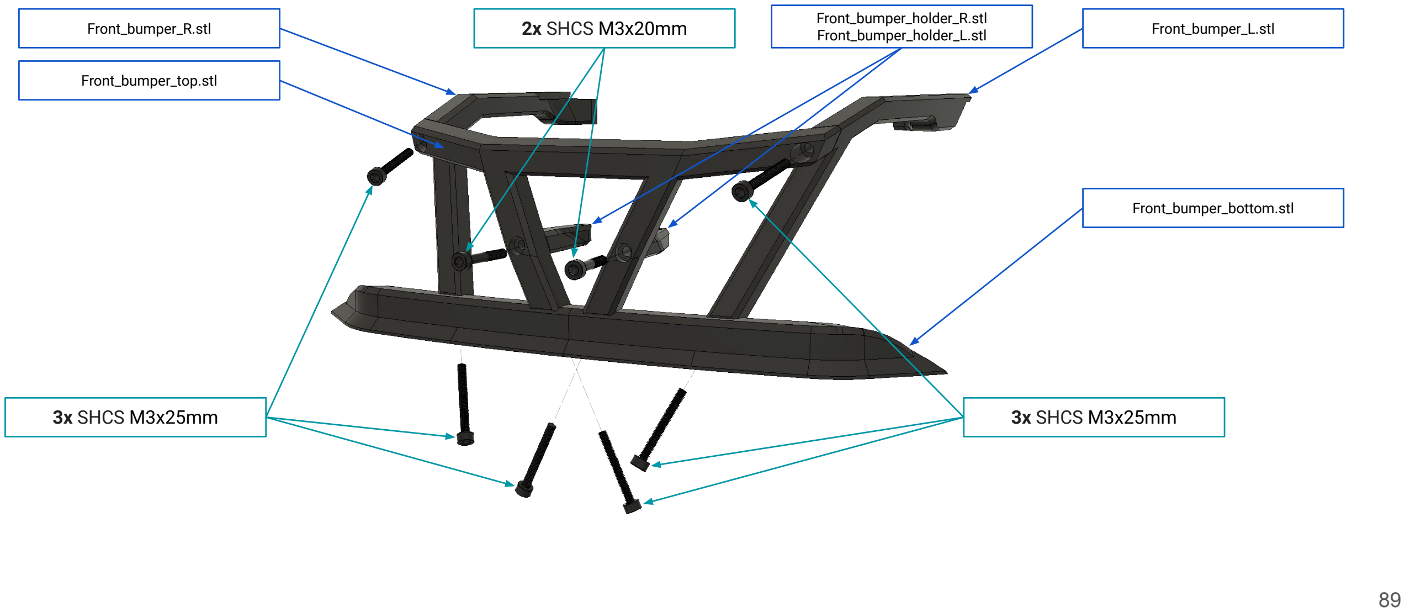
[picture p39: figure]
2x SHCS M3x20mm; 3x SHCS M3x25mm; Front_bumper_bottom.stl; Front_bumper_holder_R.stl; Front_bumper_holder_L.stl Front_bumper_R.stl; Front_bumper_L.stl; Front_bumper_top.stl

# StreetBASHER

## Chassis - Body Roll Cage

! Careful !
Screwing into plastic, do not overtighten.

# StreetBASHER

## Body Roll Cage

! Careful !
Screwing into plastic, do not overtighten.

5x SHCS M3x20mm

SHCS M3x30mm

Roof.stl

### Repeat on other side

Side_L.stl

Back_Bottom_L.stl

Back_Top_L.stl

Back_Cage.stl

M3 Hex nut

# StreetBASHER

## Body Roll Cage

SHCS M3x20mm

### Repeat on other side

2x M3 Hex nut

# StreetBASHER

## Chassis - Body Roll Cage

Body Roll Cage

# StreetBASHER

## Chassis - Body Roll Cage

### Repeat on other side ! Careful !

Screwing into plastic, do not overtighten.

4x FHCS M3x14mm

M3 Hex nut

# StreetBASHER

## Chassis - Body Roll Cage

! Careful !
Screwing into plastic, do not overtighten.

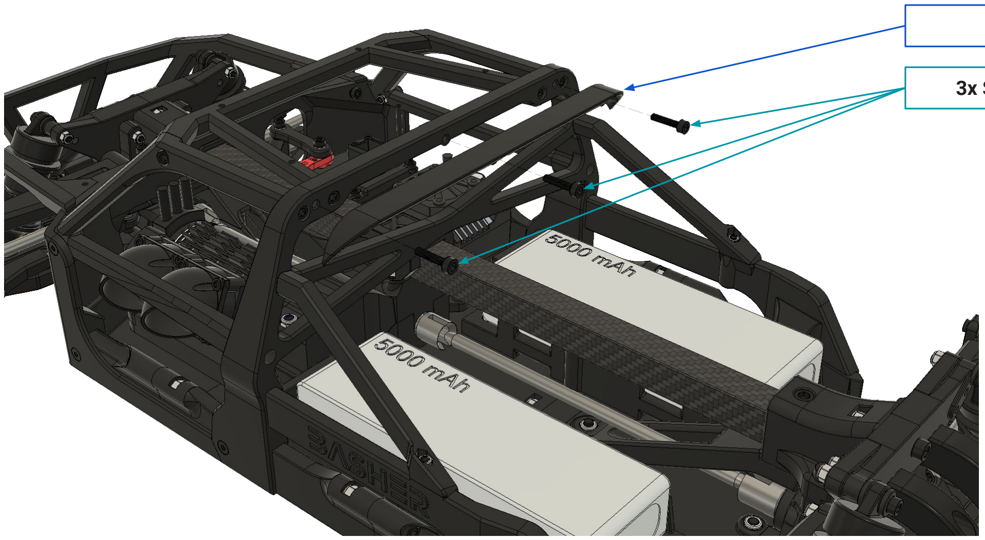
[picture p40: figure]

3x SHCS M3x14mm

Back_Roof.stl

# StreetBASHER

## Chassis - Body Roll Cage

! Careful !
Screwing into plastic, do not overtighten.

4x FHCS M3x10mm

Roof_Panel.stl

2x FHCS M3x14mm

2x FHCS M4x16mm

# StreetBASHER

## Chassis - Wheels

### Repeat on all sides

Tyre with 17mm Wheel Hex

# StreetBASHER

## Chassis - Wheels

### Repeat on all sides

Wheel Hex

# StreetBASHER

## Complete

# THANK YOU

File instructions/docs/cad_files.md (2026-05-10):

# CAD Source Files

This section provides the original SolidWorks (.sldprt) design files. These are intended for users who wish to modify the design or integrate it into larger assemblies.

---

## Chassis Designs

| Part Name | Status | Format | Link |
|---|---|---|---|
| **Center_Front_bumper** | ✅ Ready | .sldprt | [🔗](https://github.com/CagriCatik/StreetBasher/blob/main/sldprts/Center_Front_bumper.sldprt) |
| Front_body_brace_1 | ❌ In Dev | .sldprt | - |
| Front_body_brace_2 | ❌ In Dev | .sldprt | - |
| Front_body_brace_insert | ❌ In Dev | .sldprt | - |
| Front_spliter | ❌ In Dev | .sldprt | - |
| Rear_difuser_body | ❌ In Dev | .sldprt | - |
| Rear_wing_brace_L | ❌ In Dev | .sldprt | - |
| Rear_wing_brace_R | ❌ In Dev | .sldprt | - |
| Center_body | ❌ In Dev | .sldprt | - |
| Front_body | ❌ In Dev | .sldprt | - |
| Front_brace | ❌ In Dev | .sldprt | - |
| Rear_body | ❌ In Dev | .sldprt | - |
| Rear_brace | ❌ In Dev | .sldprt | - |

---

> [!NOTE]
> Additional SolidWorks files will be uploaded as they are finalized and tested. Check the [GitHub Repository](https://github.com/CagriCatik/StreetBasher) for the latest updates.

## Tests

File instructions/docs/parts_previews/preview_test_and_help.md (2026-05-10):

# Test And Help 3D Previews

Explore all Test And Help components in 3D. Drag to rotate, scroll to zoom.

---

### Fit Test

### Front Ball Insert Helper

### Rear Ball Inser Helper

### Wrench

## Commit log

2024-12-09 docs update
    [BOM_parts_StreetBASHER.xlsx, Printed_parts_StreetBASHER.xlsx]
2024-12-09 new structure
    [Back_Bottom_L.stl, Back_Bottom_R.stl, Back_Cage.stl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]
2025-03-23 update printed parts
    [Ball_Lock_x2.stl, Diff_body.stl, Diff_cover.stl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]
2026-05-10 new design
    [BOM_parts_StreetBASHER.xlsx, Back_Bottom_L.stl, Back_Bottom_R.stl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]
2026-05-10 fix: use relative paths for STL files to support GitHub Pages subfolder deployment
